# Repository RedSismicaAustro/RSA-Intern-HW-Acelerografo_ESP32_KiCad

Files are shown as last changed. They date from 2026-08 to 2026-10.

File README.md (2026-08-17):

# 🚀 Rediseño y Estandarización de PCB Acelerográfica en KiCad 10 (PCBA JLCPCB)

Este repositorio contiene el espacio de trabajo, documentación de referencia y material de apoyo para el desarrollo de la pasantía de **Joel Suárez** en la **Red Sísmica del Austro (RSA)**.

El objetivo central es capturar, auditar, optimizar y estandarizar el diseño del **Sistema Acelerográfico con ESP32 (SMD)** en el entorno **KiCad 10**, garantizando que el diseño sea 100% compatible con el firmware de adquisición original y esté preparado para ensamblaje automático (**PCBA**) en **JLCPCB**.

---

## 📂 Organización del Repositorio

Para mantener el flujo de trabajo simple y ordenado, el proyecto está estructurado en tres carpetas:

```text
RSA-Intern-HW-Acelerografo_ESP32_KiCad/
│
├── .gitignore                                 # Configurado para ignorar temporales y respaldos de KiCad
├── README.md                                  # Guía operativa e instrucciones de trabajo
│
├── docs/                                      # Documentación técnica de apoyo y planificación
│   ├── Planificacion_Migracion_EAGLE_KiCad.pdf # Plan de trabajo oficial detallado (96 horas)
│   └── especificacion_hardware_original.md    # Detalle de circuitos integrados, valores pasivos y pines
│
├── eagle/                                     # Material de referencia del diseño previo
│   ├── BOM_Assembly.txt                       # Lista de materiales (BOM) con valores, referencias y encapsulados
│   ├── images_schematic/                      # Capturas de los esquemas por bloques (Páginas 1 a 7 y Full)
│   └── images_pcb_3d_view/                    # Vistas 3D de referencia de la placa previa
│
└── kicad/                                     # 👉 Espacio de trabajo exclusivo para el nuevo proyecto KiCad 10
```

---

## 🧭 Metodología de Trabajo y Fases (96 horas)

Dado que el diseño previo proviene de una versión en Autodesk Fusion Electronics / EAGLE sin archivos de proyecto nativos disponibles, el trabajo se desarrollará directamente en **KiCad 10** en la carpeta [`kicad/`](./kicad) siguiendo estas 6 fases:

### 1. Captura de Esquemático y Auditoría de Pines (Pinout Audit - 16 h)
* **Captura en KiCad 10:** Crear el proyecto en [`kicad/`](./kicad) y dibujar los bloques esquemáticos utilizando como referencia las capturas en [`eagle/images_schematic/`](./eagle/images_schematic), la lista de materiales en [`eagle/BOM_Assembly.txt`](./eagle/BOM_Assembly.txt) y la [`especificacion_hardware_original.md`](./docs/especificacion_hardware_original.md).
* **Auditoría estricta contra Firmware:** Cotejar pin a pin la asignación de GPIOs del ESP32 con el código fuente del firmware de adquisición disponible en [RSA Sensor (GitHub)](https://github.com/JorgeZh-hub/RSA_sensor):
  * **ADXL355Z (SPI):** `MOSI`, `MISO`, `SCK`, `CS`.
  * **Tarjeta MicroSD (SPI + Buffer 74LVC125A):** `MOSI`, `MISO`, `SCK`, `CS`.
  * **GPS (UART):** `TX`, `RX`.
  * **RTC DS3231 (I2C + SQW):** `SDA`, `SCL`, interrupción `SQW` (1 Hz).
  * **Conversor USB/Serial (UART):** `TXD0`, `RXD0`, `DTR`, `RTS` hacia el CH340G.

### 2. Estandarización de Componentes y Códigos LCSC (16 h)
* Asignar a cada símbolo el campo de metadatos `LCSC` con el número de parte (*LCSC Part Number*) del catálogo de JLCPCB.
* Priorizar componentes clasificados como **Basic Parts** de JLCPCB para reducir costos de montaje.
* Seleccionar encapsulados SMD estándar adecuados (0805, 0603, 1206, SOT-23, SOIC).

### 3. Gestión de Librerías Locales Relativas (12 h)
* Utilizar la herramienta `jlc2kicadlib` para descargar componentes específicos que no estén en la librería oficial de KiCad.
* Alojar todos los símbolos (`.kicad_sym`), huellas (`.kicad_mod` en carpeta `.pretty`) y modelos 3D (`.step`) dentro de carpetas locales del proyecto (ej. `kicad/libs/`).
* Configurar las rutas mediante variables relativas del entorno KiCad (ej. `${KIPRJMOD}`) para que el repositorio sea **100% portable y autónomo** al clonarse en cualquier computador.

### 4. Layout Físico, Integridad y Optimización (24 h)
* **Desacoplo:** Ubicar condensadores de desacoplo (0.1 µF y 10 µF) lo más próximos posible a los pines `VCC`/`VDD` del ESP32, ADXL355 y RTC.
* **Plano de Masa:** Implementar planos de tierra robustos de cobre (GND) en ambas capas (Top y Bottom).
* **Señales Críticas:** Rutar con trazas cortas y directas las líneas de datos SPI del acelerómetro y MicroSD, minimizando el número de vías.
* **Test Points:** Incluir puntos de prueba accesibles (pads/headers) para señales críticas (`3.3V`, `5V`, `GND`, `TX/RX`, `SQW 1Hz`, bus SPI).
* **Pick & Place:** Colocar al menos 3 marcas fiduciarias (*Fiducials*) en las esquinas de la PCB.
* **DRC:** Ejecutar el Design Rules Check de KiCad y asegurar 0 errores/advertencias.

### 5. Generación y Validación de Archivos de Fabricación (14 h)
* Instalar y utilizar el plugin **Fabrication Toolkit** en KiCad para generar automáticamente el paquete PCBA:
  * Archivos Gerber y NC Drill.
  * Lista de Materiales (`BOM.csv`).
  * Archivo de Posición y Coordenadas (`CPL.csv`).
* Cargar el paquete en el visor web de JLCPCB para auditar y corregir rotaciones u offsets de los componentes SMD.

### 6. Cierre y Documentación (14 h)
* Documentar las decisiones técnicas y optimizaciones realizadas (planos GND, desacoplo, corrección de pines).
* Generar las instrucciones de actualización y exportación en el README final del proyecto.

---

## 🏆 Criterios de Éxito y Entregables Finales

1. **Proyecto KiCad 10 Funcional y Portable:** Esquemático y PCB completos en `kicad/` con librerías locales relativas.
2. **Paquete de Fabricación JLCPCB Validado:** Gerbers, BOM y CPL listos para producción sin requerir correcciones manuales en el visor de JLCPCB.
3. **Auditoría de Pines Verificada:** Informe que certifique la compatibilidad total del pinout con el firmware de adquisición.

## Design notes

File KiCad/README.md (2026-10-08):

# Documentación técnica del PCB acelerográfico ESP32

**Proyecto:** Rediseño y estandarización del sistema acelerográfico de la Red Sísmica del Austro (RSA).  
**Responsable del trabajo según README:** Joel Suárez.  
**Entorno de diseño:** KiCad 10.  
**Fecha de revisión documental:** 7 de octubre de 2026.  
**Estado:** documentación del diseño y paquete exportado; pendiente de certificación eléctrica, de reglas y de ensamblaje.

## 1. Introducción y organización del proyecto

Este documento describe el entorno desarrollado para el PCB acelerográfico ESP32: proyecto KiCad, alimentación, bloques funcionales, bibliotecas locales, selección de componentes y preparación de archivos para fabricación PCBA. La estructura documental toma como referencia el README del Concentrador aportado, adaptando su organización al acelerógrafo. Los componentes, el origen EAGLE/Fusion del diseño y las rutas corresponden al proyecto acelerográfico; no se trasladan los datos del circuito Concentrador.

Las fuentes técnicas son el BOM `Acelerografo_ESP32.csv`, los archivos locales KiCad y las capturas proporcionadas. La organización del repositorio corresponde al árbol de carpetas aportado:

```text
RSA-Intern-HW-Acelerografo_ESP32_KiCad/
├── docs/
├── eagle_Images/
│   ├── images_pcb_3d_view/
│   └── images_schematic/
└── KiCad/
    ├── fabrication/
    ├── libs/
    │   ├── footprint/
    │   ├── JLC2KiCad_lib/
    │   │   └── RSA.pretty/
    │   │       └── packages3d/
    │   ├── LibExt.pretty/
    │   │   └── packages3d/
    │   ├── RSA.pretty/
    │   │   └── packages3d/
    │   └── symbol/
    └── projects/
        └── Acelerografo_ESP32/
            ├── .history/
            ├── production/
            └── _restore_backup_2026-09-14T22-53-35-565/
```

| Directorio | Función en el entorno |
|---|---|
| `docs/` | Documentación técnica del proyecto. |
| `eagle_Images/` | Capturas del esquemático y vistas 3D del diseño de referencia. |
| `KiCad/fabrication/` | Directorio disponible para organizar recursos de fabricación; no se encontraron archivos durante esta revisión. |
| `KiCad/libs/` | Símbolos, huellas y modelos 3D locales. |
| `KiCad/libs/JLC2KiCad_lib/` | Recursos adicionales generados por la herramienta de importación de componentes. |
| `KiCad/projects/Acelerografo_ESP32/` | Proyecto activo: `.kicad_pro`, `.kicad_sch`, `.kicad_pcb`, BOM y tablas de bibliotecas. |
| `KiCad/projects/Acelerografo_ESP32/production/` | Paquete de fabricación exportado mediante Fabrication Toolkit. |
| `.history/` y `_restore_backup_2026-09-14T22-53-35-565/` | Historial y respaldo del proyecto; no constituyen el paquete destinado al fabricante. |

El directorio `KiCad/fabrication/` y la carpeta `production/` del proyecto son ubicaciones diferentes. Los archivos exportados inspeccionados se encuentran en la segunda.
La revisión incluyó las tablas de bibliotecas, las opciones de Fabrication Toolkit, los CSV de producción y el inventario interno del ZIP de Gerbers. No se ejecutaron ERC ni DRC, no se realizó una auditoría completa de las conexiones, no se inspeccionaron gráficamente los Gerbers ni se cargó el paquete en JLCPCB. Tampoco se comprobó el firmware ni la correspondencia comercial de cada LCSC con su encapsulado. Las instrucciones de validación de este documento son pasos pendientes, no resultados aprobados.

## 2. Objetivo del proyecto

Reconstruir, auditar y estandarizar en KiCad 10 el sistema acelerográfico con ESP32 originalmente desarrollado en Autodesk Fusion Electronics/EAGLE, empleando las capturas y documentación disponibles como referencia. La placa integra adquisición de aceleración, almacenamiento local y referencias temporales, y busca mantener la compatibilidad con el firmware original.

El objetivo de fabricación es obtener un proyecto mantenible y portable, con componentes identificados mediante códigos LCSC para el ensamblaje PCBA en JLCPCB y una lista explícita de módulos y conectores instalados manualmente. La compatibilidad con el firmware y la aptitud para fabricación requieren las verificaciones eléctricas y de ensamblaje descritas en este documento.

## 3. Arquitectura general

```text
Entrada 12 V (12V1)
        │
        ▼
Módulo MP2307 (U8, montaje manual)
        │ 5 V
        ▼
LD1117S33 (U4)
        │ 3.3 V / alimentación digital prevista
        ▼
ESP32-WROOM-32 (U1)
        ├── SPI ── ADXL355Z (U3): adquisición acelerográfica
        ├── SPI ── 74LVC125 (U7) / MicroSD1: almacenamiento
        ├── UART ─ GPS1: referencia temporal y posicionamiento
        ├── I²C / SQW ─ RTC (U2) / BT1: reloj y respaldo
        └── UART ─ CH340G (U6) / USB-C (J7): comunicación/programación
```

El diagrama sintetiza la arquitectura prevista en el README y la solicitud de diseño; no reemplaza la auditoría pin a pin. El archivo PCB declara dos capas de cobre, `F.Cu` y `B.Cu`, y un espesor nominal de 1,6 mm. Estos son parámetros del diseño, no una confirmación de fabricación.

### 3.1 Alimentación 12 V → 5 V → 3,3 V

La etapa de reducción de 12 V a 5 V se implementa con un **módulo MP2307**, representado por U8. El CSV conserva el nombre genérico `STEP_DOWN_CONVERTER`; la identificación MP2307 procede de la definición del proyecto aportada por el usuario. La vista 3D muestra una pequeña placa convertidora completa en la zona superior izquierda, con inductor y elementos de regulación propios.

El módulo sustituye la implementación discreta de la etapa conmutada y se instala manualmente. La placa principal conserva condensadores externos: C20 de 220 µF y C21 de 100 nF en la zona de entrada, y C22 de 100 µF, C23 de 100 nF y C24 de 10 nF en la zona del convertidor. Su conexión exacta debe confirmarse en el esquemático; la lista de valores no certifica por sí sola su función eléctrica.

U4, `LD1117S33TR_SOT223`, realiza la regulación prevista de 5 V a 3,3 V. Su footprint es `SOT-223-3_TabPin2` y su código LCSC es C35879. Antes de conectar la electrónica digital, medir la salida del módulo a 5 V y la salida de U4 a 3,3 V; verificar pinout, polaridad, tensión admisible de condensadores, demanda máxima de corriente y disipación térmica. Documentar también el comportamiento con alimentación USB y externa simultánea mediante la revisión de las conexiones reales.

### 3.2 Bloques visibles en la captura

| Bloque | Referencias principales | Descripción y evidencia visual |
|---|---|---|
| Entrada y regulación | 12V1, U8, U4, C20–C24 | Conector de entrada arriba a la derecha, convertidor arriba a la izquierda y regulador U4 en la zona superior. |
| Control y comunicaciones | U1 | Módulo ESP32-WROOM-32 en el borde inferior derecho, con antena hacia el exterior. Revisar keepout en ambas capas. |
| Adquisición | U3 | Huella de la placa ADXL355Z en el lateral derecho, sobre el ESP32; la ausencia de cuerpo 3D no demuestra ausencia de montaje. |
| GPS | GPS1 | Área de breakout GPS en la zona superior derecha, rotulada con PA6H y su contorno mecánico. |
| Almacenamiento | MicroSD1, U7 | Portatarjetas en el lateral izquierdo inferior y buffer próximo a él. |
| Reloj y respaldo | U2, BT1 | RTC en la zona inferior central y huella del soporte de batería en la esquina inferior izquierda. |
| USB/serial | J7, U6 | USB-C en el borde izquierdo y CH340G en la zona central izquierda. |
| Control e indicación | EN1, RTS1, D3, D4 | Dos pulsadores centrales y LEDs distribuidos en la placa. |
| Interconexión y pasivos | J6, J9, J13, J16, J17, J18; R, C, D | Headers, acceso a señales, resistencias, condensadores y diodos según el BOM. |

La captura permite describir placement y presencia de huellas, pero no demuestra continuidad de planos GND, integridad de señales, cumplimiento de reglas ni montaje real. No se asigna aquí una función específica a cada diodo o resistencia sin auditar su red.

### 3.3 PCB final — vista 3D

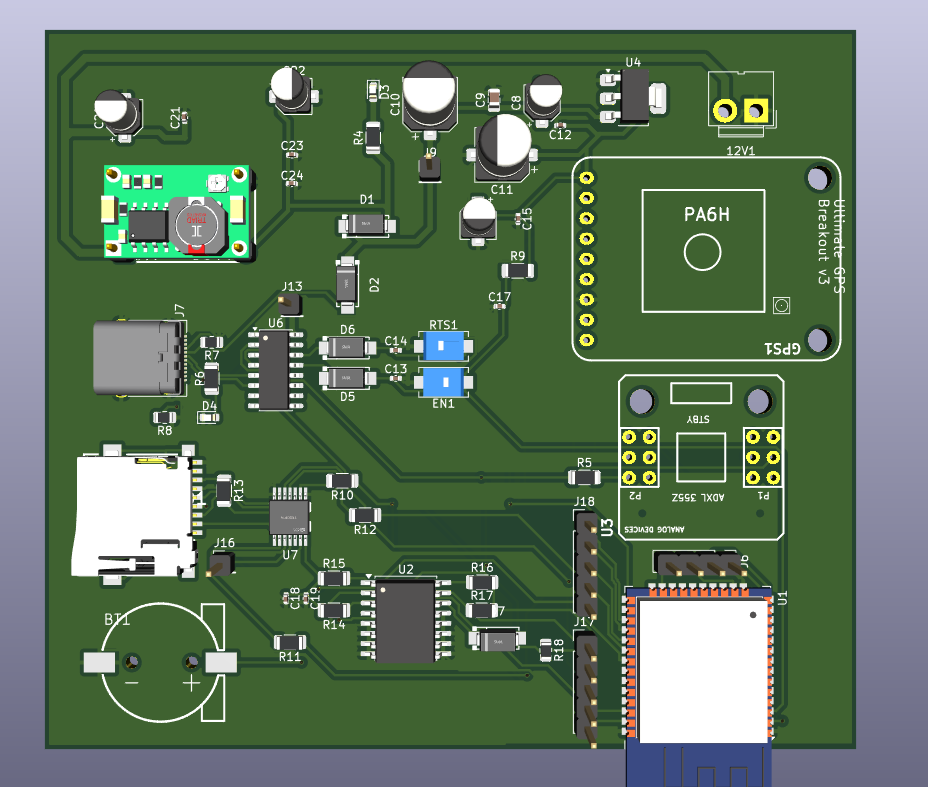
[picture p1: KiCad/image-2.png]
PCB final del acelerógrafo ESP32


**Figura: PCB final presentado por el usuario.** La vista muestra la distribución de la etapa de alimentación, el ESP32, los espacios para GPS y ADXL355, el puerto USB-C, el portatarjetas MicroSD y el RTC con soporte de batería. La imagen documenta la disposición física final mostrada; no representa una fotografía de una placa fabricada ni certifica ERC, DRC o validación en JLCPCB.
## 4. Librerías locales y portabilidad

La captura y `fp-lib-table` muestran dos bibliotecas de huellas específicas del proyecto:

| Apodo en KiCad | Directorio local | Uso identificado en el BOM |
|---|---|---|
| LibsExt | `KiCad/libs/LibExt.pretty` | Soporte CR1220, GPS_BREAKOUT_V3, MicroSD_holder, ADXL355Z y STEP_DOWN_CONVERTER. |
| LibsRSA | `KiCad/libs/RSA.pretty` | Huellas SMA para ES1D y TSSOP-14 para 74LVC125. |

`LibsExt` es el apodo; `LibExt.pretty` es el nombre real del directorio. No deben confundirse. Existen símbolos en `KiCad/libs/symbol/`, un archivo `KiCad/libs/RSA.kicad_sym` y modelos en subdirectorios `packages3d` de las bibliotecas.

**Estado observado:** las tablas aún utilizan rutas absolutas `C:/Users/Suarezc1224/Desktop/...`. Por tanto, la portabilidad no está completada. Además, `sym-lib-table` apunta a directorios para LibsExt y LibsRSA, en lugar de identificar archivos `.kicad_sym`; esta configuración requiere revisión y prueba de resolución de símbolos.

Como el proyecto reside en `KiCad/projects/Acelerografo_ESP32/`, las rutas relativas propuestas son:

```text
LibsExt (huellas): ${KIPRJMOD}/../../libs/LibExt.pretty
LibsRSA (huellas): ${KIPRJMOD}/../../libs/RSA.pretty
LibsRSA (símbolos, si se adopta RSA.kicad_sym): ${KIPRJMOD}/../../libs/RSA.kicad_sym
Modelo 3D local, ejemplo: ${KIPRJMOD}/../../libs/LibExt.pretty/packages3d/Convertidor STEP DOWN.step
```

Para los símbolos externos, registrar cada archivo `.kicad_sym` con el apodo correspondiente, o consolidarlos en una biblioteca válida y actualizar sus identificadores. No apuntar una biblioteca de símbolos KiCad a una carpeta como sustituto de un archivo. Mantener los apodos utilizados por los componentes o reasignarlos de forma coherente.

Después de ajustar las rutas, abrir una copia del repositorio en una ubicación distinta, comprobar símbolos, huellas y vista 3D, y revisar que no queden rutas personales. Los modelos oficiales que usan `${KICAD10_3DMODEL_DIR}` requieren las bibliotecas estándar correspondientes en el equipo receptor. Estas correcciones se documentan como propuestas; no se modificaron los archivos del proyecto durante esta tarea.

## 5. Flujo técnico del entorno desarrollado

El entorno reúne el proyecto KiCad, las bibliotecas locales, el BOM y los archivos de fabricación. Su organización permite mantener la relación entre el circuito, los componentes físicos y el paquete destinado a producción.

1. **Esquemático:** el archivo `Acelerografo_ESP32.kicad_sch` contiene la representación del circuito. Desde el editor se gestionan referencias, valores, conexiones y asignación de huellas.
2. **Bibliotecas:** `KiCad/libs/` reúne símbolos, huellas y modelos 3D. Las tablas del proyecto registran LibsExt y LibsRSA; las rutas relativas propuestas en la sección anterior facilitan trasladar el entorno a otro equipo.
3. **Componentes:** el campo LCSC identifica las piezas previstas para PCBA. Los módulos y conectores de montaje manual se mantienen en la BOM completa, separados del conjunto que se enviará a ensamblaje.
4. **PCB:** `Acelerografo_ESP32.kicad_pcb` contiene la distribución física y el ruteo. La captura 3D permite identificar los bloques y su disposición en la placa.
5. **Exportación:** Fabrication Toolkit genera el paquete en `production/`, con Gerbers, taladros, BOM y posiciones de componentes.
6. **Actualización:** después de cambiar el circuito o el layout, actualizar el PCB desde el esquemático, ejecutar las comprobaciones técnicas y regenerar el paquete para mantener los archivos de fabricación coherentes con el diseño.

Se confirmó la existencia de estos recursos. La revisión documental no incluyó la ejecución de las comprobaciones eléctricas ni la modificación de los archivos KiCad.
### 5.1 Configuración del entorno de trabajo

Abrir `KiCad/projects/Acelerografo_ESP32/Acelerografo_ESP32.kicad_pro` con KiCad 10. Mantener las bibliotecas estándar utilizadas por los footprints del BOM y registrar las bibliotecas locales en las tablas específicas del proyecto. Revisar la resolución de símbolos, huellas y modelos antes de actualizar el circuito.

Para la importación de componentes, disponer de Python y JLC2KiCadLib. Si se utiliza un entorno virtual, puede prepararse desde la raíz del repositorio:

```powershell
python -m venv .venv
.\.venv\Scripts\Activate.ps1
python -m pip install JLC2KiCadLib
jlc2kicadlib --help
```

Estos comandos describen la preparación del entorno y no se ejecutaron en esta revisión. La versión de Python debe ser compatible con la versión instalada de la herramienta; no se presupone que el entorno del Concentrador sea idéntico al del acelerógrafo.

El entorno incluye Fabrication Toolkit para exportar el paquete desde el editor PCB. Si se prepara otro equipo, instalar el complemento desde el administrador de complementos y contenidos de KiCad y comprobar que esté disponible en el editor.

### 5.2 Campos de componentes y mantenimiento

Mantener `Reference`, `Value`, `Footprint` y `LCSC` coherentes entre esquemático, PCB y exportación. `Qty` es la cantidad agrupada en el BOM. Los campos Datasheet, Description, fabricante y número de parte pueden complementar la identificación sin sustituir el LCSC ni el encapsulado real.

Los elementos manuales conservan su huella en la placa. Para excluirlos de los archivos de ensamblaje, revisar sus atributos de BOM y de posición según la configuración mostrada en la sección de fabricación. Mantener una BOM completa independiente para documentar tanto las piezas PCBA como las de instalación posterior.

Las bibliotecas compartidas se deben actualizar de forma controlada; después de cambiar una huella, comprobar pads, numeración, posición y modelo 3D. Mantener las modificaciones locales versionadas junto al proyecto.
## 6. Lista completa de componentes

La tabla se transcribe del CSV aportado sin sustituir valores ni footprints. Hay **32 filas agrupadas, 59 componentes físicos, 22 códigos LCSC únicos**, con **47 componentes previstos para JLCPCB** y **12 para montaje manual**. `—` representa una celda originalmente vacía. MicroSD1 tiene el campo Value vacío en el CSV.

Un código LCSC indica selección de catálogo y destino de ensamblaje previsto; no certifica stock, categoría Basic/Extended, compatibilidad de footprint ni aceptación del pedido.

### 6.1 Componentes con LCSC — ensamblaje JLCPCB previsto

| Reference | Qty | Value | Footprint | LCSC |
|---|---:|---|---|---|
| BT1 | 1 | Battery | LibsExt:CR1220-2-ext | C70381 |
| C8,C16 | 2 | 10uF | Capacitor_SMD:CP_Elec_4x5.4 | C3343 |
| C9 | 1 | 200nF | Capacitor_SMD:C_0805_2012Metric | C344170 |
| C10,C11 | 2 | 100uF | Capacitor_SMD:CP_Elec_6.3x7.7 | C3338 |
| C12,C13,C14,C15,C17,C19,C21,C23 | 8 | 100nF | Capacitor_SMD:C_0402_1005Metric | C1525 |
| C18 | 1 | 1uF | Capacitor_SMD:C_0402_1005Metric | C29266 |
| C20 | 1 | 220uF | Capacitor_SMD:CP_Elec_4x5.4 | C2858857 |
| C22 | 1 | 100uF | Capacitor_SMD:CP_Elec_4x5.4 | C970695 |
| C24 | 1 | 10nF | Capacitor_SMD:C_0402_1005Metric | C15195 |
| D1,D2,D5,D6,D7 | 5 | ES1D | LibsRSA:SMA_L4.4-W2.8-LS5.4-RD | C64878 |
| D3,D4 | 2 | LED | LED_SMD:LED_0603_1608Metric | C2290 |
| EN1,RTS1 | 2 | SW_Push | Button_Switch_SMD:SW_SPST_EVQPE1 | C720477 |
| MicroSD1 | 1 | — | LibsExt:MicroSD_holder | C53223918 |
| R4,R6,R14,R15,R16,R17 | 6 | 4.7k | Resistor_SMD:R_1206_3216Metric | C17936 |
| R5,R9 | 2 | 10k | Resistor_SMD:R_1206_3216Metric | C17902 |
| R7,R8 | 2 | 5.1k | Resistor_SMD:R_0805_2012Metric | C27834 |
| R10,R11,R12,R13 | 4 | 3.3k | Resistor_SMD:R_1206_3216Metric | C26010 |
| R18 | 1 | 200 | Resistor_SMD:R_0805_2012Metric | C17540 |
| U2 | 1 | DS3231M | Package_SO:SOIC-16W_7.5x10.3mm_P1.27mm | C9866 |
| U4 | 1 | LD1117S33TR_SOT223 | Package_TO_SOT_SMD:SOT-223-3_TabPin2 | C35879 |
| U6 | 1 | CH340G | Package_SO:SOIC-16_3.9x9.9mm_P1.27mm | C14267 |
| U7 | 1 | 74LVC125 | LibsRSA:TSSOP-14_L5.0-W4.4-P0.65-LS6.4-BL | C7813 |

### 6.2 Componentes sin LCSC — montaje manual / DNP-PCBA

Los campos LCSC vacíos son intencionales: estos módulos, conectores y elementos externos se excluyen del ensamblaje JLCPCB y se instalan posteriormente. DNP-PCBA significa que no se montan en fábrica, aunque sí forman parte del producto terminado. MicroSD1 y BT1 pertenecen a la tabla anterior porque tienen LCSC; no se excluyen por su categoría física.

| Reference | Qty | Value | Footprint | LCSC |
|---|---:|---|---|---|
| 12V1 | 1 | Conn_01x02 | Connector:JWT_A3963_1x02_P3.96mm_Vertical | — |
| GPS1 | 1 | GPS_BREAKOUT_V3 | LibsExt:GPS_BREAKOUT_V3 | — |
| J6 | 1 | Conn_01x04_Pin | Connector_PinHeader_2.54mm:PinHeader_1x04_P2.54mm_Vertical | — |
| J7 | 1 | USB_C_Receptacle | Connector_USB:USB_C_Receptacle_Amphenol_12401610E4-2A | — |
| J9 | 1 | IN_LD | Connector_PinHeader_2.54mm:PinHeader_1x01_P2.54mm_Vertical | — |
| J13,J16 | 2 | Conn_01x01_Pin | Connector_PinHeader_2.54mm:PinHeader_1x01_P2.54mm_Vertical | — |
| J17,J18 | 2 | Conn_01x05_Pin | Connector_PinHeader_2.54mm:PinHeader_1x05_P2.54mm_Vertical | — |
| U1 | 1 | ESP32-WROOM-32 | RF_Module:ESP32-WROOM-32 | — |
| U3 | 1 | ADXL355Z | LibsExt:ADXL355Z | — |
| U8 | 1 | STEP_DOWN_CONVERTER | LibsExt:STEP_DOWN_CONVERTER | — |

## 7. Importación con jlc2kicadlib

El siguiente comando PowerShell incluye exactamente los 22 códigos únicos del BOM, conservando el orden de primera aparición y los parámetros solicitados. Documenta una operación reproducible; no se ejecutó durante la generación de este informe.

```powershell
jlc2kicadlib `
C70381 C3343 C344170 C3338 C1525 C29266 C2858857 C970695 C15195 C64878 C2290 C720477 C53223918 C17936 C17902 C27834 C26010 C17540 C9866 C35879 C14267 C7813 `
-dir "C:\Users\Suarezc1224\Desktop\RSA-Intern-HW-Acelerografo_ESP32_KiCad\KiCad\libs" `
-symbol_lib RSA `
-symbol_lib_dir . `
-footprint_lib RSA.pretty `
-model_dir packages3d `
--skip_existing
```

Ejecutar en PowerShell con la herramienta instalada y sin espacios después de los acentos graves de continuación. Si cambia la ubicación del repositorio, ajustar `-dir`. Conservar `--skip_existing` y revisar el registro de importación; no asumir que actualiza o corrige componentes ya presentes. La descarga no sustituye la revisión de pinout, pads, orientación y dimensiones. Confirmar las rutas generadas de los modelos 3D y registrar las bibliotecas resultantes bajo los apodos del proyecto.

## 8. Carpeta production y Fabrication Toolkit

La carpeta `KiCad/projects/Acelerografo_ESP32/production/` contiene el paquete generado mediante **Fabrication Toolkit**, según el flujo descrito por el usuario y la presencia de sus opciones de exportación. **Sí se inspeccionó su contenido real a nivel de listado, CSV y entradas del ZIP.** No se realizó una inspección gráfica ni una validación de fabricación.

Los nombres genéricos `BOM.csv` y `CPL.csv` describen los entregables de materiales y posiciones; los archivos existentes usan los nombres siguientes:

| Archivo real | Función |
|---|---|
| `JLPCB_Acele-ESP32.zip` | Paquete de Gerbers y NC Drill. |
| `JLPCB_Acele-ESP32_bom.csv` | Equivalente funcional a BOM.csv: referencias, footprint, cantidad, valor y LCSC. |
| `JLPCB_Acele-ESP32_positions.csv` | Equivalente funcional a CPL.csv: Designator, Mid X, Mid Y, Rotation y Layer. |
| `JLPCB_Acele-ESP32_designators.csv` | Archivo auxiliar de designadores; se confirmó su presencia, sin evaluar su contenido. |
| `netlist.ipc` | Netlist auxiliar; se confirmó su presencia, sin validar conectividad. |

Dentro del ZIP se encontraron:

```text
Acelerografo_ESP32-F_Cu.gtl
Acelerografo_ESP32-B_Cu.gbl
Acelerografo_ESP32-F_Mask.gts
Acelerografo_ESP32-B_Mask.gbs
Acelerografo_ESP32-F_Paste.gtp
Acelerografo_ESP32-B_Paste.gbp
Acelerografo_ESP32-F_Silkscreen.gto
Acelerografo_ESP32-B_Silkscreen.gbo
Acelerografo_ESP32-Edge_Cuts.gm1
Acelerografo_ESP32-PTH.drl
Acelerografo_ESP32-NPTH.drl
Acelerografo_ESP32-PTH-drl_map.gbr
Acelerografo_ESP32-NPTH-drl_map.gbr
```

Los archivos `.drl` corresponden a taladros metalizados (PTH) y no metalizados (NPTH); los mapas asociados apoyan su revisión. No hay archivos literalmente llamados `BOM.csv` o `CPL.csv` en el listado revisado: deben seleccionarse sus equivalentes al cargar el pedido.

### 8.1 Configuración de exclusión y exportación mostrada

En las propiedades del componente, la captura aportada muestra activados **Excluir de la lista de materiales** y **Excluir de los archivos de posición**. **Excluir de la placa** permanece desactivado: el componente conserva su lugar físico en el PCB para el montaje manual.

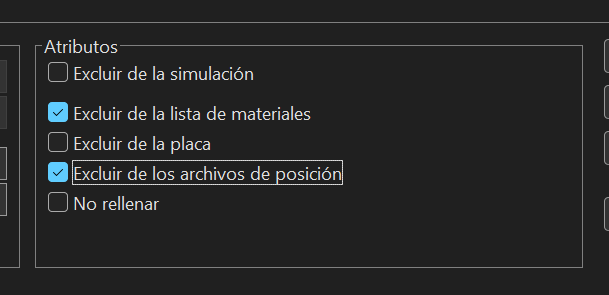
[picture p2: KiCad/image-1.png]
Atributos para excluir elementos manuales de BOM y posiciones


Esta captura ilustra los atributos de un elemento; no demuestra por sí sola que se hayan aplicado a todas las referencias manuales. La exclusión de BOM y posición debe comprobarse para cada elemento de ese grupo. No equivale automáticamente a marcar DNP.

En Fabrication Toolkit se muestra el nombre de exportación **Acelerografo_V1_RevA** y las siguientes opciones:

| Opción | Estado visible |
|---|---|
| Apply automatic component translations | Activada. |
| Apply automatic fill for all zones | Activada. |
| Exclude DNP components from BOM | Activada. |
| Open browser after generation | Activada. |
| Generate backup files | Activada. |
| Plot all active layers | Desactivada. |
| Set User.1 as V-Cut layer | Desactivada. |
| Set User.2 as alternative Edge-Cut layer | Desactivada. |

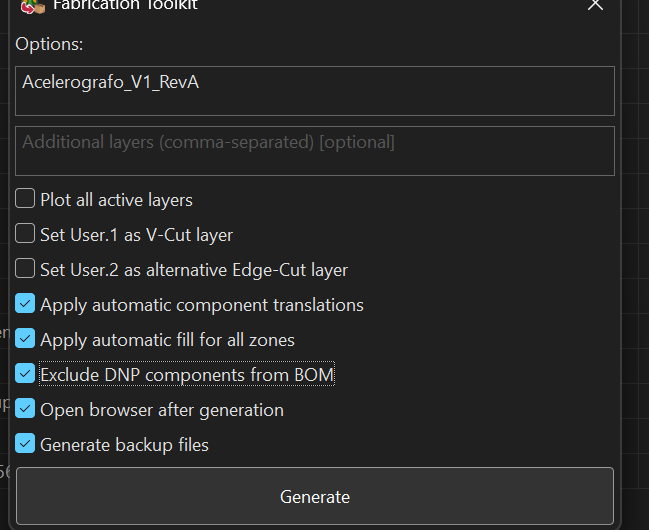
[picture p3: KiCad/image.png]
Configuración de Fabrication Toolkit para Acelerografo_V1_RevA


Después de revisar los atributos y guardar el diseño, ejecutar **Generate**, comprobar el directorio de salida y revisar el contenido del BOM y del CPL. Conservar junto al paquete la revisión del proyecto de la que se exportó.

**Diferencia entre la captura y los archivos inspeccionados:** la nueva captura muestra exclusión DNP activada y el nombre `Acelerografo_V1_RevA`. El archivo de opciones todavía disponible en disco conserva `EXCLUDE DNP: false` y `ARCHIVE_NAME: JLPCB Acele-ESP32`; los archivos encontrados en `production/` usan el prefijo `JLPCB_Acele-ESP32`. Por tanto, la captura documenta la configuración presentada, pero no confirma que el paquete existente se haya regenerado con ella. No se encontró un paquete con el nombre nuevo en el listado revisado.

### 8.2 Observaciones del paquete existente en disco

- El BOM de producción todavía contiene las 32 filas, incluidos los componentes manuales sin LCSC. La opción `EXCLUDE DNP` figura como `false` en `fabrication-toolkit-options.json`. Los campos LCSC vacíos no prueban por sí solos que estos componentes se excluirán del pedido.
- El archivo de posiciones tiene 56 referencias, todas en `top`; incluye componentes de montaje manual. GPS1, U3 y U8 no aparecen en ese archivo. Para el pedido final, comprobar que BOM y CPL contengan exactamente el conjunto autorizado para PCBA.
- MicroSD1 aparece como `MICROSD1` en los archivos de producción y con valor `~`. Normalizar/verificar referencias y completar su descripción en el flujo de pedido sin confundir el marcador con una especificación comercial.
- Debe verificarse cada combinación LCSC/Value/Footprint contra la ficha del fabricante y la selección de JLCPCB. Esta revisión no certifica, por ejemplo, la correspondencia del nombre `DS3231M` con el encapsulado SOIC-16W indicado en el BOM.

Para obtener el paquete definitivo, marcar los componentes manuales como excluidos de PCBA mediante los atributos admitidos por la versión instalada del plugin, activar la exclusión aplicable y regenerar. Alternativamente, preparar BOM y CPL filtrados coherentemente para ensamblaje, conservando por separado la BOM completa. Confirmar el resultado exportado; no basta con cambiar una opción. No se modificó el paquete original durante esta tarea.

## 9. ERC y auditoría eléctrica

1. Abrir el proyecto y resolver las bibliotecas de símbolos antes de revisar el circuito.
2. Ejecutar ERC desde el editor de esquemáticos y registrar fecha, versión, errores y advertencias.
3. Revisar alimentación, pines sin conexión, nombres de red, salidas enfrentadas, entradas flotantes y pines de potencia. Utilizar marcas de no conexión y PWR_FLAG solo cuando el circuito lo justifique.
4. Auditar la cadena 12 V → módulo MP2307 → 5 V → LD1117S33 → 3,3 V, pinout del módulo, masas, polaridad y protección. Comprobar interacción entre USB y fuente externa.
5. Comparar con el firmware GPIO de ADXL355 y MicroSD por SPI, GPS por UART, RTC por I²C/SQW y CH340G por UART/DTR/RTS. Registrar una tabla de señal, GPIO, pin físico y evidencia de firmware.
6. Corregir incidencias y repetir ERC; justificar cualquier exclusión de forma individual. Actualizar el PCB desde el esquemático.

**Resultado de ERC en esta revisión: no ejecutado.** No se declara cero errores ni compatibilidad de firmware verificada.

## 10. DRC y revisión física

1. Seleccionar las reglas de fabricación del servicio y stackup que se contratarán: separación, anchos, vías, taladros y distancias a bordes.
2. Rellenar zonas de cobre y ejecutar DRC en el editor PCB; revisar conexiones sin rutear, cortocircuitos, separaciones, taladros, contorno y courtyards.
3. Revisar continuidad y retornos de GND en ambas capas, desacoplos cercanos a los pines, longitud de SPI y ubicación del acelerómetro respecto de la etapa conmutada.
4. Comprobar keepout de antena ESP32, interferencias mecánicas, acceso a USB/MicroSD, altura de módulos, polaridad y pin 1. Revisar los puntos de prueba y la disposición de fiduciales para el ensamblaje.
5. Resolver errores y advertencias o registrar la justificación técnica de cada excepción.
6. Guardar la revisión aprobada y regenerar todos los archivos de producción desde ella.

**Resultado de DRC en esta revisión: no ejecutado.** La vista 3D y el ZIP existente no acreditan cumplimiento de reglas.

## 11. Validación del pedido en JLCPCB

1. Cargar el ZIP de Gerbers y revisar capas, dimensiones, contorno, máscara, serigrafía y taladros en el visor. Confirmar dos capas y espesor previsto de 1,6 mm según el pedido elegido.
2. Elegir ensamblaje en las caras que correspondan al diseño final; la exportación actual contiene posiciones en top.
3. Cargar el BOM de PCBA y el CPL coherentes, excluyendo las 12 referencias físicas de montaje manual. Mantener su lista para la instalación posterior.
4. Verificar para cada LCSC valor, part number, fabricante, encapsulado, stock y clasificación Basic/Extended. Resolver el Value vacío de MicroSD1 y cualquier incompatibilidad detectada.
5. Revisar la vista de ensamblaje referencia por referencia: coordenadas, unidades, origen, cara, rotación, pin 1 y polaridad. No interpretar automáticamente las coordenadas Y negativas como error; comprobar su resultado en el visor.
6. Comprobar que ninguna pieza manual figure en el ensamblaje solicitado, que no falte ninguna pieza aprobada y que cantidades de BOM y CPL coincidan.
7. Archivar capturas del visor, BOM/CPL aceptados, revisión del proyecto y lista de incidencias resueltas antes de aprobar la fabricación.

**Estado de validación JLCPCB: pendiente; no se cargó ni se aprobó un pedido en esta tarea.**

## 12. Montaje manual y puesta en marcha

Tras recibir la placa ensamblada, inspeccionar soldaduras y orientación de componentes. Instalar 12V1, GPS1, J6, J7, J9, J13, J16, J17, J18, U1, U3 y U8 conforme al esquema y a la lista de montaje manual. Revisar especialmente el sentido de entrada/salida del convertidor y los conectores de módulos.

Antes de energizar, comprobar ausencia de cortocircuitos en las líneas de alimentación. Verificar 5 V y 3,3 V con alimentación controlada antes de conectar los módulos sensibles. Después, comprobar programación y comunicación del ESP32, lectura de los tres ejes del acelerómetro, escritura/lectura de MicroSD, comunicación GPS y funcionamiento del RTC y su respaldo. Registrar mediciones, versión de firmware y resultados.

## 13. Estado técnico de los archivos del entorno

| Elemento | Estado documental observado |
|---|---|
| Proyecto KiCad y vista 3D | Disponibles; revisión eléctrica integral pendiente. |
| BOM completa | 32 filas / 59 componentes, transcrita en este documento. |
| Separación de montaje | 47 componentes PCBA previstos / 12 manuales documentados; exclusión en exportación pendiente. |
| Importación LCSC | Comando preparado con 22 códigos únicos; no ejecutado aquí. |
| Librerías locales | Presentes; rutas absolutas y entradas de símbolos por corregir/verificar. |
| Fabrication Toolkit / production | Paquete presente e inventariado; inspección gráfica y aceptación pendientes. |
| ERC / DRC | Sin resultados certificados en esta revisión. |
| Firmware y pruebas de banco | Pendientes de auditoría y evidencia. |

La liberación para fabricación requiere completar la portabilidad, auditar las partes y conexiones, cerrar ERC/DRC, regenerar BOM/CPL con exclusión coherente del montaje manual y validar el paquete en JLCPCB.

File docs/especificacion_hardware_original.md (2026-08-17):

# 📋 Especificación Técnica Original del Hardware (Versión Previa)

Este documento recopila la especificación técnica de los circuitos, componentes e interfaces de comunicación desarrollados en la etapa previa del diseño acelerográfico SMD. Sirve como referencia directa para la captura y estandarización en KiCad 10.

---

## 1. Arquitectura y Protocolos de Comunicación

El hardware integra el microcontrolador **ESP32** con sensores y periféricos mediante tres buses principales:

| Periférico | Protocolo | Líneas / Señales |
|---|---|---|
| **Acelerómetro ADXL355Z** | SPI | `SCLK`, `MOSI`, `MISO`, `CS` |
| **Tarjeta MicroSD** | SPI (vía buffer 74LVC125A) | `SCLK`, `MOSI`, `MISO`, `CS` |
| **Módulo GPS (FPGMMOPA6H)** | UART | `TX_GPS`, `RX_GPS` |
| **RTC DS3231** | I2C + Interrupción | `SDA`, `SCL`, `SQW` (1 Hz) |
| **Conversor USB-C / Serial** | UART (CH340G) | `TXD0`, `RXD0`, `DTR`, `RTS` |

> 🔗 **Repositorio de Firmware de Referencia:** [RSA Sensor (GitHub)](https://github.com/JorgeZh-hub/RSA_sensor)  
> *Nota Crítica:* Todos los pines del ESP32 asignados en KiCad deben coincidir con la configuración de GPIOs de este firmware.

---

## 2. Sistema de Alimentación

El circuito opera a dos niveles principales de tensión:
1. **Entrada Principal (+12V DC):** Conector XH de 2 pines con protección por diodos.
2. **Etapa Buck (+12V a +5V):** Regulador conmutado basado en el circuito integrado **MP2307** (eficiencia ~85%).
3. **Etapa Lineal (+5V a +3.3V):** Regulador lineal LDO **LD33V** (encapsulado SOT-223) para alimentar el ESP32, sensores y periféricos digitales.
4. **Alimentación USB-C:** Entrada alternativa de +5V por USB con diodos de protección para permitir programación y depuración sin conectar los +12V.

---

## 3. Circuitos Integrados (ICs) Principales

* **ESP32-WROOM-32E:** Microcontrolador SMD con conectividad Wi-Fi y antena externa.
* **ADXL355Z:** Acelerómetro triaxial de bajo ruido y alta resolución (SPI).
* **DS3231:** Reloj en tiempo real de alta precisión con oscilador TCXO integrado (SOIC-16) y batería de respaldo.
* **MP2307:** Regulador Buck Step-Down síncrono (SOIC-8 Exposed Pad).
* **LD33V:** Regulador de voltaje lineal de +3.3V (SOT-223).
* **CH340G:** Puente USB a UART para programación/depuración (SOP-16).
* **74LVC125A:** Buffer cuádruple de nivel lógico con salidas tri-state (TSSOP-14) para aislar las líneas SPI de la tarjeta MicroSD.

---

## 4. Lista de Componentes Pasivos y Semiconductores

### Resistencias
* `R1`, `R3`: 8.2 kΩ (SMD 2512)
* `R2`: 100 kΩ (SMD 2512)
* `R4`: 220 kΩ (Potenciómetro / Trimmer de ajuste)
* `R5`, `R6`, `R7`, `R8`: 3.3 kΩ (SMD 1206) - Pull-ups / Limitadoras
* `R9`, `R10`, `R11`, `R12`, `R16`: 4.7 kΩ (SMD 1206) - Pull-ups I2C y líneas de control
* `R13`: 200 Ω (SMD 1206) - Resistencia limitadora LED
* `R14`, `R15`: 5.11 kΩ (SMD 1206) - Pull-downs de configuración USB-C CC1/CC2
* `R17`: 4.7 kΩ (SMD 2512)
* `R18`, `R19`: 10 kΩ (SMD 1206)

### Capacitores
* `C1`, `C7`, `C9`, `C13`, `C15`, `C16`, `C18`, `C19`: 100 nF (0.1 µF) - Desacoplo de alta frecuencia
* `C2`, `C3`, `C17`: 10 µF - Filtrado y estabilización
* `C4`: 200 nF (0.2 µF)
* `C5`, `C6`: 100 µF - Filtrado de entrada/salida de potencia
* `C8`, `C12`: 12 µF
* `C10`: 4.7 nF
* `C11`: 10 nF
* `C14`: 1 µF

### Inductor y Diodos
* `L1`: 2 µH (SMD 0805) - Inductor de filtro/conmutación
* `D1`, `D3`, `D4`: Diodos rápidos 1N4148 (SMD SOD-123 / SMA)
* `D5`, `D6`: Diodos rectificadores 1N4001 / S1M (SMA/DO-214AC)
* `D2`, `D7`: LEDs indicadores de estado y encendido (SMD 1206)

---

## 5. Puntos de Prueba (Test Points) Implementados

Para la depuración física con osciloscopio o multímetro se requieren puntos de prueba en:
1. **Líneas SPI:** `SCK`, `MOSI`, `MISO`, `CS_ADXL355`, `CS_SD`.
2. **Líneas UART / GPS:** `TX_GPS`, `RX_GPS`, `TXD0`, `RXD0`.
3. **Líneas I2C / Reloj:** `SDA`, `SCL`, señal `SQW` (1 Hz).
4. **Alimentación y Tierra:** `GND`, `+3.3V`, `+5V`, `+12V`.

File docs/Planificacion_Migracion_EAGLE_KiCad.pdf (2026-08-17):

Migración de EAGLE a KiCad

Contexto y Antecedentes

Este proyecto consiste en la continuación, consolidación y optimización del trabajo desarrollado en las etapas previas del sistema de registro continuo de señales acelerométricas:

- Proyecto de Adquisición de Datos (https://github.com/RedSismicaAustro/RSA-Intern-Acelerografo_ESP32) (Firmware y Software): Diseñó el circuito en protoboard y el firmware de adquisición basado en el microcontrolador ESP32, el acelerómetro ADXL355, un RTC, un GPS y almacenamiento en tarjeta SD. Este diseño en protoboard demostró un funcionamiento correcto y estable de la adquisición.
- Proyecto de Diseño de PCB en EAGLE: (https://github.com/RedSismicaAustro/RSA-Intern-HW-Acelerografo_ESP32_SMD) Tomó como referencia el circuito del Proyecto de Adquisición de Datos y diseñó la PCB en EAGLE, estructurándola en una versión modular (con módulos prefabricados) y una versión optimizada en SMD (con componentes de montaje superficial individuales).
- Proyecto de Migración de EDA (https://github.com/RedSismicaAustro/RSA-Intern-SHM) (Altium a KiCad): Estableció el entorno de trabajo estándar de la RSA para la migración de proyectos EDA a KiCad 10, implementando el uso de jlc2kicadlib para la descarga local de componentes y el plugin Fabrication Toolkit para la generación de archivos de ensamblaje automático (PCBA) en JLCPCB.

Objetivo del Proyecto

El objetivo principal de esta pasantía consiste en migrar el diseño de PCB en EAGLE hacia el entorno KiCad 10, aplicando las directrices de estandarización para PCBA en JLCPCB.

Un requerimiento crítico es auditar, corregir y optimizar el diseño migrado para asegurar que sea 100% compatible y trabaje correctamente con el firmware y hardware del Proyecto de Adquisición de Datos original. Esto implica garantizar que la asignación de pines y las líneas de señal/alimentación estén optimizadas para evitar ruidos o pérdidas de datos en la adquisición física final.

Plan de Trabajo Detallado (96 horas)

Fase 1: Importación Nativa y Auditoría de Pines de Hardware/Firmware (16 h)

Objetivo: Migrar los esquemas originales de EAGLE a KiCad y auditar minuciosamente las conexiones para garantizar compatibilidad directa con el firmware del sistema de adquisición.

- Importación nativa: Utilizar la herramienta integrada en KiCad 10 para cargar el esquemático (.sch) y la placa (.brd) de la versión SMD del diseño original.
- Auditoría de asignación de pines (Pinout Audit):
- Comparar de forma exhaustiva las conexiones del ESP32 en el esquemático importado con la asignación de pines (GPIOs) definida en el firmware del Proyecto de Adquisición de Datos.
- Verificar las líneas de comunicación SPI con el ADXL355 (MISO, MOSI, SCK, CS), la interfaz UART con el GPS (TX, RX), el bus I2C y el pin SQW (1 Hz) del RTC, y los pines de control/datos de la tarjeta SD.
- Corregir cualquier discrepancia o pin erróneamente conectado en el esquema para asegurar que la placa final ejecute el firmware original sin necesidad de modificar el código de adquisición de datos.

- Resolución de jerarquías y conectividad: Depurar etiquetas de red, buses y puertos de alimentación para asegurar la integridad eléctrica del diseño.

Fase 2: Estandarización de Componentes SMD y Asignación de Códigos LCSC (16 h)

Objetivo: Adaptar y estandarizar todos los componentes para compatibilidad PCBA de JLCPCB.

- Inventario de componentes: Catalogar los componentes pasivos y activos del circuito para su transición a SMD.
- Estandarización de encapsulados: Seleccionar encapsulados estándar de montaje superficial (ej. 0805, 0603, SOT-23, SOIC) que soporten los niveles de potencia y voltaje requeridos por el circuito en protoboard original.
- Inyección de metadatos LCSC: Añadir de forma masiva el campo personalizado LCSC en todos los símbolos del esquemático.
- Asignación del catálogo: Buscar y asignar los números de parte (LCSC Part Number) en el catálogo de JLCPCB, priorizando el inventario de Basic Parts para optimizar los costos de manufactura.

Fase 3: Gestión de Librerías Locales Relativas (12 h)

Objetivo: Asegurar la portabilidad completa del proyecto mediante el uso de librerías locales y rutas relativas.

- Descarga automatizada: Usar scripts basados en jlc2kicadlib para descargar símbolos (.kicad_sym), huellas (.kicad_mod) y modelos 3D (.step) de los componentes no estándar.
- Estructura local del repositorio: Almacenar los archivos en la carpeta /libs en la raíz del repositorio.
- Rutas relativas: Configurar el proyecto de KiCad utilizando rutas relativas (ej. variables como ${KIPRJMOD}) para que el repositorio sea autónomo al clonarse en cualquier estación de trabajo.
- Auditoría física de huellas: Verificar físicamente la correspondencia geométrica, la posición del Pin 1 y la orientación de los modelos 3D en relación con el footprint.

Fase 4: Optimización del Ruteo, Diseño Físico y Mejoras de Funcionamiento (24 h)

Objetivo: Optimizar el layout físico de la PCB en KiCad para garantizar la correcta adquisición de señales y reducir el ruido en condiciones de trabajo reales.

- Optimización y corrección de la integridad física:
- Planos de alimentación y desacoplo: Añadir o reubicar condensadores de desacoplo de montaje superficial (0.1µF y 10µF) lo más cerca posible de los pines de alimentación (VCC) del ESP32, el acelerómetro ADXL355 y el RTC para filtrar el ruido de la fuente de alimentación.
- Integridad en señales críticas: Rutar de manera directa y con el mínimo uso de vías las líneas de datos de alta velocidad (bus SPI a 250 Hz del ADXL355 y bus de la tarjeta SD) para evitar atenuaciones de señal o pérdidas de tramas.
- Plano de masa robusto: Implementar zonas de cobre dedicadas para la masa (GND) en ambas capas (Top y Bottom) con el fin de minimizar bucles de tierra y blindar el ruido de conmutación electromagnética de la antena del ESP32.

- Puntos de prueba (Test Points): Colocar puntos de prueba accesibles en las líneas críticas (GND, 3.3V, 5V, TX/RX, señal SQW a 1 Hz, y líneas de control de SPI) para facilitar la depuración física con osciloscopio o multímetro.
- Layout y Ensamblaje:
- Colocar al menos 3 marcas fiduciarias (Fiducials) en las esquinas de la placa para calibración visual de las máquinas Pick & Place.
- Ejecutar la Verificación de Reglas de Diseño (DRC) y corregir el 100% de las alertas.

Fase 5: Generación y Validación de Archivos de Fabricación (14 h)

Objetivo: Generar la documentación técnica exacta de producción y validar su visualización final en JLCPCB.

- Generación automatizada: Utilizar el plugin Fabrication Toolkit para exportar:
- Archivos Gerber completos y archivos de perforación NC Drill.
- Lista de Materiales (BOM.csv) formateada con designador, cantidad, footprint, LCSC Part Number y valor.
- Archivo de Coordenadas de Posición (CPL.csv) para colocación de componentes SMD.
- Validación de offsets y rotación: Subir el paquete de archivos al visor web de JLCPCB y validar visualmente la alineación de todos los componentes SMD en la placa.
- Corrección de offsets: Ajustar las rotaciones en el Fabrication Toolkit (ej. desvíos de 90∘ o 180∘ )
hasta que el alineamiento sea idéntico al diseño físico.

Fase 6: Cierre y Documentación Técnica (14 h)

Objetivo: Consolidar la documentación del proyecto migrado para asegurar la reproducibilidad y el mantenimiento.

- Auditoría final comparativa: Documentar formalmente las mejoras de diseño (condensadores de desacoplo, corrección de pines, ruteo optimizado) realizadas con respecto al diseño original de PCB en EAGLE.
- README Operativo del Proyecto: Elaborar el archivo README en la raíz detallando:
- Versión exacta de KiCad utilizada (v10).
- Instrucciones detalladas de instalación y configuración de jlc2kicadlib.
- Resumen de la asignación de pines auditada y validada contra el firmware.
- Guía paso a paso para regenerar los archivos de fabricación mediante el plugin.

Entregables del Pasante (Criterios de Éxito)

Para considerar la migración como aprobada y lista para producción, el pasante deberá proporcionar:

1. Repositorio Autónomo y Portable:
- Archivos de esquemático y PCB completos y funcionales en KiCad 10 con la asignación de pines corregida y auditada.
- Carpeta local | /libs | con símbolos, huellas y modelos 3D con direccionamiento estrictamente
relativo.
2. Paquete de Fabricación Validador (Production Release):
- Archivos Gerber, NC Drill, BOM.csv y CPL.csv listos para ser subidos y procesados por JLCPCB sin correcciones manuales intermedias.
3. Documento Técnico de Auditoría y README:
- README en la raíz que explique el entorno y la estructura.
- Breve informe de auditoría que garantice que la asignación de pines en la PCB coincide exactamente con el firmware de adquisición de datos original, detallando las optimizaciones de ruido y desacoplo aplicadas en la placa.

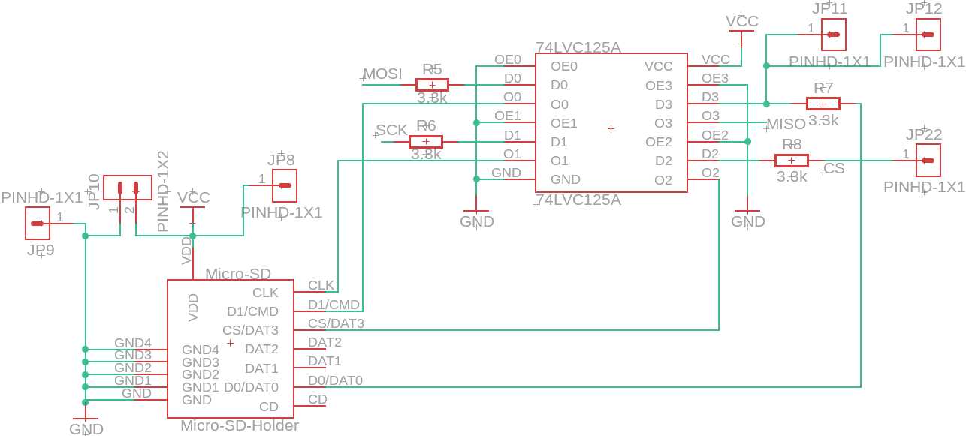
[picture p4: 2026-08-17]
eagle_Images/images_schematic/schematic_6.png

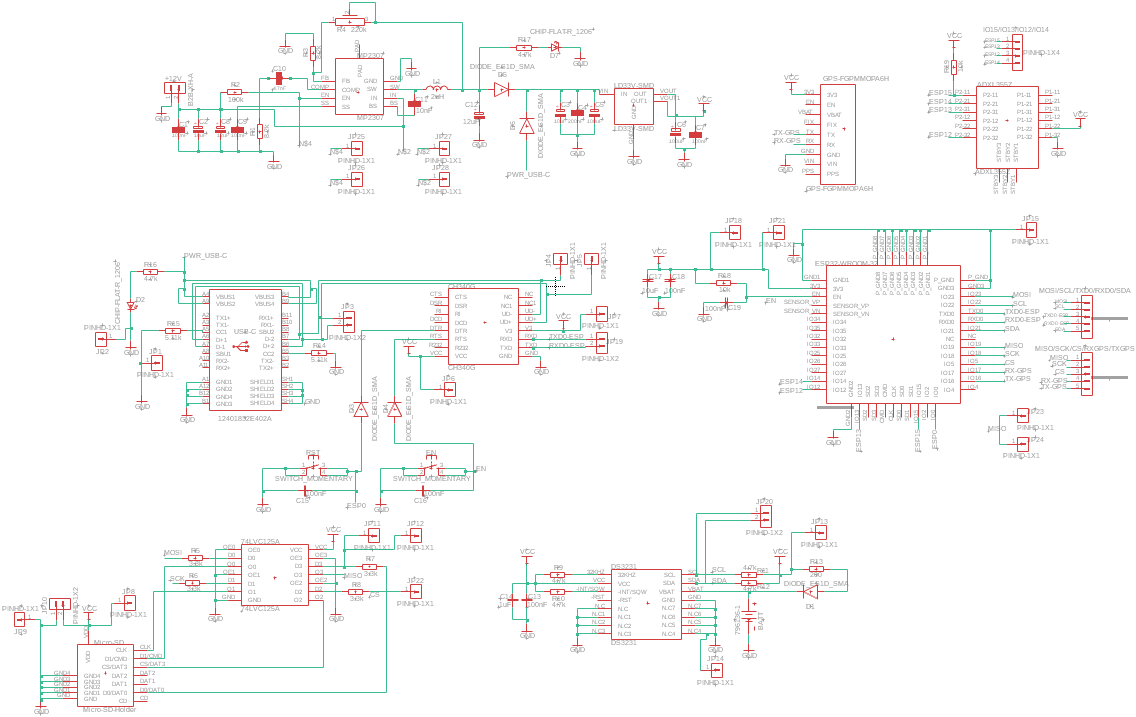
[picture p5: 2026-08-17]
eagle_Images/images_schematic/schematic_Full.png

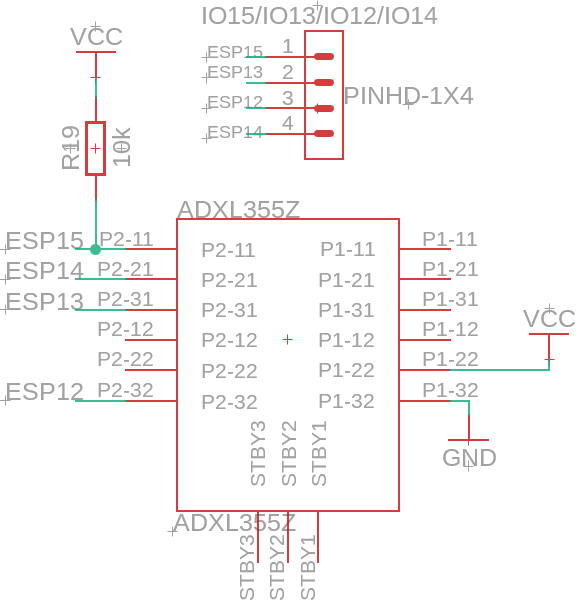
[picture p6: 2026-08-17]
eagle_Images/images_schematic/schematic_3.png

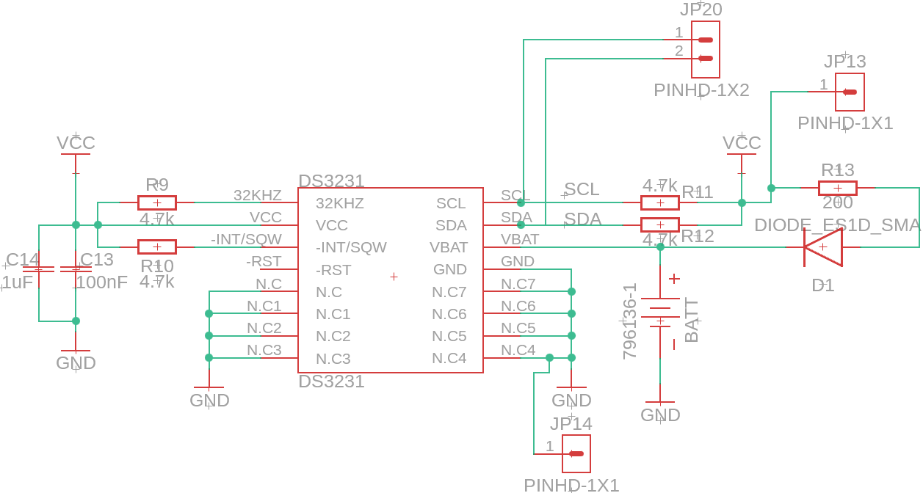
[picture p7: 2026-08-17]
eagle_Images/images_schematic/schematic_7.png

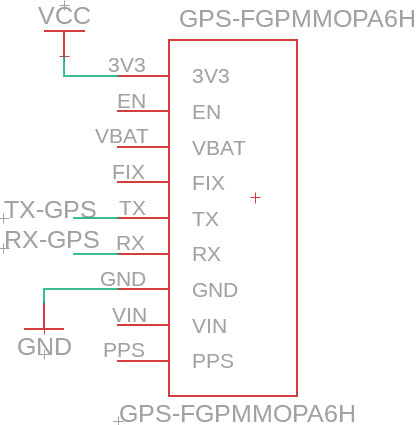
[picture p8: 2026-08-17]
eagle_Images/images_schematic/schematic_2.png

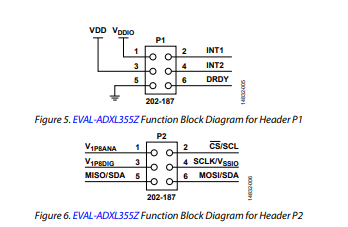
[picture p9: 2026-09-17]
eagle_Images/images_schematic/39320436-b1bcb230-4949-11e8-9dc2-eba227ff7d66.png

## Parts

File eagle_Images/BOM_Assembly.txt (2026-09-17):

"Partlist exported " "from Centro de Fusion: Christian_U Proyecto: PCB_SMD Placa: " "SMD_V1 v116 at 7/6/2025 0:18"                                                                                                                                                                                                                                                                                                                                                                                                                                                                                                                                                                                                                                                                                                                                                                                                                                                                                                                                                                                                                                                                                         
                                                                                                                                                                                                                                                                                                                                                                                                                                                                                                                                                                                                                                                                                                                                                                                                                                                                                                                                                                                                                                                                                                                                                                                                           
"Qty Value         " "   Device                           Package                 " "   Parts                                                                                                                      " "Description                   " "                   " "CATEGORY        " "CELL_DIAMETER " "COLOR " "CONTACTS " "CURRENT_RATING " "DATASHEET                                                                                                 " "DESCRIPTION        " "    " "    " "    " "  " "     " "    " "    " "   " "           " "  " "     " "      " "           " "          " "   " "         " "        " "       " "      " "       " "        " "     " "FORWARD_CURRENT " "FORWARD_VOLTAGE " "GENDER     " "MANUFACTURER " "            " "          " "MATERIAL_CORE " "MPN           " "OPERATING_TEMP " "OPERATING_TEMPERATURE " "PACKAGE_SIZE " "PACKAGE_TYPE  " "PART_STATUS " "PITCH            "  "RATING " "REVERSE_VOLTAGE " "ROHS      " "ROHS_COMPLIANT " "SERIES " "SUB-CATEGORY " "SUBCATEGORY             " "TEMPERATURE_COEFFICIENT " "THERMALLOSS " "TOLERANCE " "TYPE    " "            " "              " "     " "VOLTAGE_RATING " "ZENER_VOLTAGE" 
"1   100k          " "   RESISTOR__CHIP-2512(6332-METRIC) RESC6332X71             " "   R2                                                                                                                         " "Resistor Fixed - Generic      " "                   " "Resistor        " "              " "      " "         " "               " "                                                                                                          " "                   " "    " "    " "    " "  " "     " "    " "    " "   " "           " "  " "     " "      " "           " "          " "   " "         " "        " "       " "      " "       " "        " "     " "                " "                " "           " "             " "            " "          " "              " "              " "               " "                      " "             " "              " "            " "                 "  "       " "                " "          " "               " "       " "Fixed        " "                        " "                        " "            " "          " "        " "            " "              " "     " "               " "             " 
"3   100nF         " "   CAPACITORCERAMIC-2.54MM          CAP-THRU-2.54MM         " "   C1, C7, C9                                                                                                                 " "Capacitor - Generic           " "                   " "                " "              " "      " "         " "               " "                                                                                                          " "                   " "    " "    " "    " "  " "     " "    " "    " "   " "           " "  " "     " "      " "           " "          " "   " "         " "        " "       " "      " "       " "        " "     " "                " "                " "           " "             " "            " "          " "              " "              " "               " "                      " "             " "              " "            " "                 "  "       " "                " "          " "               " "       " "             " "                        " "                        " "            " "          " "        " "            " "              " "     " "               " "             " 
"5   100nF         " "   C_CHIP-0603(1608-METRIC)         CAPC1608X85             " "   C13, C15, C16, C18, C19                                                                                                    " "Capacitor - Generic           " "                   " "Capacitor       " "              " "      " "         " "               " "                                                                                                          " "                   " "    " "    " "    " "  " "     " "    " "    " "   " "           " "  " "     " "      " "           " "          " "   " "         " "        " "       " "      " "       " "        " "     " "                " "                " "           " "             " "            " "          " "              " "              " "               " "                      " 603             "Surface Mount " "            " "                 "  "       " "                " "          " "               " "       " "             " "Ceramic Capacitors      " "                        " "            " "          " "MLCC    " "            " "              " "     " "               " "             " 
"2   100uF         " "   CAPACITOR-POLRADIAL-5MM-DIA      CAPPRD254W65D500H1150B  " "   C5, C6                                                                                                                     " "Capacitor Polarised - Generic " "                   " "                " "              " "      " "         " "               " "                                                                                                          " "                   " "    " "    " "    " "  " "     " "    " "    " "   " "           " "  " "     " "      " "           " "          " "   " "         " "        " "       " "      " "       " "        " "     " "                " "                " "           " "             " "            " "          " "              " "              " "               " "                      " "             " "              " "            " "                 "  "       " "                " "          " "               " "       " "             " "                        " "                        " "            " "          " "        " "            " "              " "     " "               " "             " 
"2   10k           " "   RESISTOR__CHIP-1206(3216-METRIC) RESC3216X70             " "   R18, R19                                                                                                                   " "Resistor Fixed - Generic      " "                   " "Resistor        " "              " "      " "         " "               " "                                                                                                          " "                   " "    " "    " "    " "  " "     " "    " "    " "   " "           " "  " "     " "      " "           " "          " "   " "         " "        " "       " "      " "       " "        " "     " "                " "                " "           " "             " "            " "          " "              " "              " "               " "                      " "             " "              " "            " "                 "  "       " "                " "          " "               " "       " "Fixed        " "                        " "                        " "            " "          " "        " "            " "              " "     " "               " "             " 
"1   10nF          " "   CAPACITORCERAMIC-2.54MM          CAP-THRU-2.54MM         " "   C11                                                                                                                        " "Capacitor - Generic           " "                   " "                " "              " "      " "         " "               " "                                                                                                          " "                   " "    " "    " "    " "  " "     " "    " "    " "   " "           " "  " "     " "      " "           " "          " "   " "         " "        " "       " "      " "       " "        " "     " "                " "                " "           " "             " "            " "          " "              " "              " "               " "                      " "             " "              " "            " "                 "  "       " "                " "          " "               " "       " "             " "                        " "                        " "            " "          " "        " "            " "              " "     " "               " "             " 
"2   10uF          " "   CAPACITOR-POLRADIAL-5MM-DIA      CAPPRD254W65D500H1150B  " "   C2, C3                                                                                                                     " "Capacitor Polarised - Generic " "                   " "                " "              " "      " "         " "               " "                                                                                                          " "                   " "    " "    " "    " "  " "     " "    " "    " "   " "           " "  " "     " "      " "           " "          " "   " "         " "        " "       " "      " "       " "        " "     " "                " "                " "           " "             " "            " "          " "              " "              " "               " "                      " "             " "              " "            " "                 "  "       " "                " "          " "               " "       " "             " "                        " "                        " "            " "          " "        " "            " "              " "     " "               " "             " 
"1   10uF          " "   C_CHIP-1206(3216-METRIC)         CAPC3216X135            " "   C17                                                                                                                        " "Capacitor - Generic           " "                   " "Capacitor       " "              " "      " "         " "               " "                                                                                                          " "                   " "    " "    " "    " "  " "     " "    " "    " "   " "           " "  " "     " "      " "           " "          " "   " "         " "        " "       " "      " "       " "        " "     " "                " "                " "           " "             " "            " "          " "              " "              " "               " "                      " 1206            "Surface Mount " "            " "                 "  "       " "                " "          " "               " "       " "             " "Ceramic Capacitors      " "                        " "            " "          " "MLCC    " "            " "              " "     " "               " "             " 
"1   12401832E402A " "   12401832E402A                    12401832E402A           " "   USB-C                                                                                                                      " "USB(3.1) Type-C- RCPT- 24POS- " "SMD-THT-R/A        " "USB Connector   " "              " "      " 24          "5A             " "https://cdn.amphenol-cs.com/media/wysiwyg/files/documentation/datasheet/inputoutput/io_usb_3_2_type_c.pdf " "USB-C (USB TYPE-C) " "USB " "3.2 " "Gen " 2    "(USB " "3.1 " "Gen " "2- " "Superspeed " "+ " "(USB " "3.1)) " "Receptacle " "Connector " 24    "Position " "Surface " "Mount- " "Right " "Angle- " "Through " "Hole " "                " "                " "Receptacle " "Amphenol ICC " "(Commercial " "Products) " "              " "12401832E402A " "               " "-40? ~ 85?            " "NA           " "SMD           " "ACTIVE      " "                 "  "       " "                " "COMPLIANT " "               " "NA     " "             " "USB TYPE-C              " "                        " "            " "          " "Surface " "Mount-Right " "Angle-Through " "Hole " "NA             " "             " 
"2   12uF          " "   CAPACITOR-POLRADIAL-5MM-DIA      CAPPRD254W65D500H1150B  " "   C8, C12                                                                                                                    " "Capacitor Polarised - Generic " "                   " "                " "              " "      " "         " "               " "                                                                                                          " "                   " "    " "    " "    " "  " "     " "    " "    " "   " "           " "  " "     " "      " "           " "          " "   " "         " "        " "       " "      " "       " "        " "     " "                " "                " "           " "             " "            " "          " "              " "              " "               " "                      " "             " "              " "            " "                 "  "       " "                " "          " "               " "       " "             " "                        " "                        " "            " "          " "        " "            " "              " "     " "               " "             " 
"1   1uF           " "   C_CHIP-0603(1608-METRIC)         CAPC1608X85             " "   C14                                                                                                                        " "Capacitor - Generic           " "                   " "Capacitor       " "              " "      " "         " "               " "                                                                                                          " "                   " "    " "    " "    " "  " "     " "    " "    " "   " "           " "  " "     " "      " "           " "          " "   " "         " "        " "       " "      " "       " "        " "     " "                " "                " "           " "             " "            " "          " "              " "              " "               " "                      " 603             "Surface Mount " "            " "                 "  "       " "                " "          " "               " "       " "             " "Ceramic Capacitors      " "                        " "            " "          " "MLCC    " "            " "              " "     " "               " "             " 
"1   200           " "   RESISTOR__CHIP-1206(3216-METRIC) RESC3216X70             " "   R13                                                                                                                        " "Resistor Fixed - Generic      " "                   " "Resistor        " "              " "      " "         " "               " "                                                                                                          " "                   " "    " "    " "    " "  " "     " "    " "    " "   " "           " "  " "     " "      " "           " "          " "   " "         " "        " "       " "      " "       " "        " "     " "                " "                " "           " "             " "            " "          " "              " "              " "               " "                      " "             " "              " "            " "                 "  "       " "                " "          " "               " "       " "Fixed        " "                        " "                        " "            " "          " "        " "            " "              " "     " "               " "             " 
"1   200nF         " "   CAPACITORCERAMIC-2.54MM          CAP-THRU-2.54MM         " "   C4                                                                                                                         " "Capacitor - Generic           " "                   " "                " "              " "      " "         " "               " "                                                                                                          " "                   " "    " "    " "    " "  " "     " "    " "    " "   " "           " "  " "     " "      " "           " "          " "   " "         " "        " "       " "      " "       " "        " "     " "                " "                " "           " "             " "            " "          " "              " "              " "               " "                      " "             " "              " "            " "                 "  "       " "                " "          " "               " "       " "             " "                        " "                        " "            " "          " "        " "            " "              " "     " "               " "             " 
"1   220k          " "   PV36P                            PV36P                   " "   R4                                                                                                                         " "Rectangular Trimmer Potentiome" "ters - PV36 Series " "Potentiometers  " "              " "      " "         " "               " "https://www.bourns.com/docs/Product-Datasheets/pv36.pdf                                                   " "0.5W 1/2W PC Pins T" "hrou" "gh H" "ole " "Tr" "immer" " Pot" "enti" "ome" "ter Cermet " 25   ".0 Tu" "rn Sid" "e Adjustmen" "t         " "   " "         " "        " "       " "      " "       " "        " "     " "                " "                " "           " "Bourns Inc.  " "            " "          " "              " "PV36Px        " "               " "-55﯃ ~ 125﯃         NA" "           TH" "T           AC" "TIVE        " "                 "  "       " "              CO" "MPLIANT   " "             PV" 36        "           Tr" "immer Potentiometers  ﯱ0" "0ppm/﯃              0.5 " "W       ﯱ0% " "     Side " "Adjustme" "nt Triangle " "Leads         " "     " "               " "        "      
"1   2uH           " "   L_CHIP-0805(2012-METRIC)         INDC2009X120            " "   L1                                                                                                                         " "Inductor Fixed - Generic      " "                   " "Inductors       " "              " "      " "         " "               " "                                                                                                          " "Chip  2.00 X 0.90 X" " 1.2" "0 mm" " bod" "y " "0805(" 2012   "-MET" "RIC" ")          " "  " "     " "      " "           " "          " "   " "         " "        " "       " "      " "       " "        " "     " "                " "                " "           " "             " "            " "          " "              " "              " "               " "                      " 805             "Surface Mount " "            " "                 "  "       " "                " "          " "               " "       " "             " "                        " "                        " "            " "          " "        " "            " "              " "     " "               " "             " 
"4   3.3k          " "   RESISTOR__CHIP-1206(3216-METRIC) RESC3216X70             " "   R5, R6, R7, R8                                                                                                             " "Resistor Fixed - Generic      " "                   " "Resistor        " "              " "      " "         " "               " "                                                                                                          " "                   " "    " "    " "    " "  " "     " "    " "    " "   " "           " "  " "     " "      " "           " "          " "   " "         " "        " "       " "      " "       " "        " "     " "                " "                " "           " "             " "            " "          " "              " "              " "               " "                      " "             " "              " "            " "                 "  "       " "                " "          " "               " "       " "Fixed        " "                        " "                        " "            " "          " "        " "            " "              " "     " "               " "             " 
"5   4.7k          " "   RESISTOR__CHIP-1206(3216-METRIC) RESC3216X70             " "   R9, R10, R11, R12, R16                                                                                                     " "Resistor Fixed - Generic      " "                   " "Resistor        " "              " "      " "         " "               " "                                                                                                          " "                   " "    " "    " "    " "  " "     " "    " "    " "   " "           " "  " "     " "      " "           " "          " "   " "         " "        " "       " "      " "       " "        " "     " "                " "                " "           " "             " "            " "          " "              " "              " "               " "                      " "             " "              " "            " "                 "  "       " "                " "          " "               " "       " "Fixed        " "                        " "                        " "            " "          " "        " "            " "              " "     " "               " "             " 
"1   4.7k          " "   RESISTOR__CHIP-2512(6332-METRIC) RESC6332X71             " "   R17                                                                                                                        " "Resistor Fixed - Generic      " "                   " "Resistor        " "              " "      " "         " "               " "                                                                                                          " "                   " "    " "    " "    " "  " "     " "    " "    " "   " "           " "  " "     " "      " "           " "          " "   " "         " "        " "       " "      " "       " "        " "     " "                " "                " "           " "             " "            " "          " "              " "              " "               " "                      " "             " "              " "            " "                 "  "       " "                " "          " "               " "       " "Fixed        " "                        " "                        " "            " "          " "        " "            " "              " "     " "               " "             " 
"1   4.7nF         " "   CAPACITORCERAMIC-2.54MM          CAP-THRU-2.54MM         " "   C10                                                                                                                        " "Capacitor - Generic           " "                   " "                " "              " "      " "         " "               " "                                                                                                          " "                   " "    " "    " "    " "  " "     " "    " "    " "   " "           " "  " "     " "      " "           " "          " "   " "         " "        " "       " "      " "       " "        " "     " "                " "                " "           " "             " "            " "          " "              " "              " "               " "                      " "             " "              " "            " "                 "  "       " "                " "          " "               " "       " "             " "                        " "                        " "            " "          " "        " "            " "              " "     " "               " "             " 
"2   5.11k         " "   RESISTOR__CHIP-1206(3216-METRIC) RESC3216X70             " "   R14, R15                                                                                                                   " "Resistor Fixed - Generic      " "                   " "Resistor        " "              " "      " "         " "               " "                                                                                                          " "                   " "    " "    " "    " "  " "     " "    " "    " "   " "           " "  " "     " "      " "           " "          " "   " "         " "        " "       " "      " "       " "        " "     " "                " "                " "           " "             " "            " "          " "              " "              " "               " "                      " "             " "              " "            " "                 "  "       " "                " "          " "               " "       " "Fixed        " "                        " "                        " "            " "          " "        " "            " "              " "     " "               " "             " 
"1   74LVC125A     " "   74LVC125A                        74LVC125A               " "   74LVC125A                                                                                                                  " "                              " "                   " "                " "              " "      " "         " "               " "                                                                                                          " "                   " "    " "    " "    " "  " "     " "    " "    " "   " "           " "  " "     " "      " "           " "          " "   " "         " "        " "       " "      " "       " "        " "     " "                " "                " "           " "             " "            " "          " "              " "              " "               " "                      " "             " "              " "            " "                 "  "       " "                " "          " "               " "       " "             " "                        " "                        " "            " "          " "        " "            " "              " "     " "               " "             " 
"1   796136-1      " "   796136-1                         796136-1                " "   BATT                                                                                                                       " "Battery Holder - Coin Cell SMD" " 20.0mm            " "Battery Holders " "20.0mm        " "      " "         " "               " "https://www.te.com/en/product-796136-1.datasheet.pdf                                                      " "Battery Holder (Ope" "n) C" "oin " "20.0" "mm" " 1 Ce" "ll S" "MD (" "SMT" ") Tab      " "  " "     " "      " "           " "          " "   " "         " "        " "       " "      " "       " "        " "     " "                " "                " "           " "TE Connectivi" "ty AMP Conne" "ctors     " "              " "796136-1      " "               " "-40﯃ ~ 85﯃          20" "32         Su" "rface Mount Ac" "tive        " "                 "  "       " "              Co" "mpliant   " "             AM" "P      " "           Co" "in Cell Holder          " "                        " "            " "        Re" "tainer  " "            " "              " "     " "               " "           "
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

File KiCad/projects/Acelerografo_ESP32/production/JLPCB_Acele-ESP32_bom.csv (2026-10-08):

Designator | Footprint | Quantity | Value | LCSC Part #
12V1 | JWT_A3963_1x02_P3.96mm_Vertical | 1 | Conn_01x02
BT1 | CR1220-2-ext | 1 | Battery | C70381
C10, C11 | CP_Elec_6.3x7.7 | 2 | 100uF | C3338
C12, C13, C14, C15, C17, C19, C21, C23 | 0402 | 8 | 100nF | C1525
C16, C8 | CP_Elec_4x5.4 | 2 | 10uF | C3343
C18 | 0402 | 1 | 1uF | C29266
C20 | CP_Elec_4x5.4 | 1 | 220uF | C2858857
C22 | CP_Elec_4x5.4 | 1 | 100uF | C970695
C24 | 0402 | 1 | 10nF | C15195
C9 | 0805 | 1 | 200nF | C344170
D1, D2, D5, D6, D7 | SMA_L4.4-W2.8-LS5.4-RD | 5 | ES1D | C64878
D3, D4 | 0603 | 2 | LED | C2290
EN1, RTS1 | SW_SPST_EVQPE1 | 2 | SW_Push | C720477
GPS1 | GPS_BREAKOUT_V3 | 1 | GPS_BREAKOUT_V3
J13, J16 | PinHeader_1x01_P2.54mm_Vertical | 2 | Conn_01x01_Pin
J17, J18 | PinHeader_1x05_P2.54mm_Vertical | 2 | Conn_01x05_Pin
J6 | PinHeader_1x04_P2.54mm_Vertical | 1 | Conn_01x04_Pin
J7 | USB_C_Receptacle_Amphenol_12401610E4-2A | 1 | USB_C_Receptacle
J9 | PinHeader_1x01_P2.54mm_Vertical | 1 | IN_LD
MICROSD1 | MicroSD_holder | 1 | ~ | C53223918
R10, R11, R12, R13 | 1206 | 4 | 3.3k | C26010
R14, R15, R16, R17, R4, R6 | 1206 | 6 | 4.7k | C17936
R18 | 0805 | 1 | 200 | C17540
R5, R9 | 1206 | 2 | 10k | C17902
R7, R8 | 0805 | 2 | 5.1k | C27834
U1 | ESP32-WROOM-32 | 1 | ESP32-WROOM-32
U2 | SOIC-16W_7.5x10.3mm_P1.27mm | 1 | DS3231M | C9866
U3 | ADXL355Z | 1 | ADXL355Z
U4 | SOT-223-3_TabPin2 | 1 | LD1117S33TR_SOT223 | C35879
U6 | SOIC-16_3.9x9.9mm_P1.27mm | 1 | CH340G | C14267
U7 | TSSOP-14_L5.0-W4.4-P0.65-LS6.4-BL | 1 | 74LVC125 | C7813
U8 | STEP_DOWN_CONVERTER | 1 | STEP_DOWN_CONVERTER

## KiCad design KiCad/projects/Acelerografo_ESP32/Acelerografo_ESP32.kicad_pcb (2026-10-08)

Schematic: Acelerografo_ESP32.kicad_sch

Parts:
12V1: Conn_01x02; JWT_A3963_1x02_P3.96mm_Vertical
BT1: Battery; CR1220-2-ext; LCSC C70381
C8, C16: 10uF; CP_Elec_4x5.4; LCSC C3343
C9: 200nF; C_0805_2012Metric; LCSC C344170
C10, C11: 100uF; CP_Elec_6.3x7.7; LCSC C3338
C12, C13, C14, C15, C17, C19, C21, C23: 100nF; C_0402_1005Metric; LCSC C1525
C18: 1uF; C_0402_1005Metric; LCSC C29266
C20: 220uF; CP_Elec_4x5.4; LCSC C2858857
C22: 100uF; CP_Elec_4x5.4; LCSC C970695
C24: 10nF; C_0402_1005Metric; LCSC C15195
D1, D2, D5, D6, D7: ES1D; SMA_L4.4-W2.8-LS5.4-RD; LCSC C64878
D3, D4: LED; LED_0603_1608Metric; LCSC C2290
EN1: SW_Push; SW_SPST_EVQPE1; LCSC C720477
GPS1: GPS_BREAKOUT_V3
J6: Conn_01x04_Pin; PinHeader_1x04_P2.54mm_Vertical
J7: USB_C_Receptacle; USB_C_Receptacle_Amphenol_12401610E4-2A
J9: IN_LD; PinHeader_1x01_P2.54mm_Vertical
J13, J16: Conn_01x01_Pin; PinHeader_1x01_P2.54mm_Vertical
J17, J18: Conn_01x05_Pin; PinHeader_1x05_P2.54mm_Vertical
MicroSD1: MicroSD_holder; LCSC C53223918
R4, R6, R14, R15, R16, R17: 4.7k; R_1206_3216Metric; LCSC C17936
R5, R9: 10k; R_1206_3216Metric; LCSC C17902
R7, R8: 5.1k; R_0805_2012Metric; LCSC C27834
R10, R11, R12, R13: 3.3k; R_1206_3216Metric; LCSC C26010
R18: 200; R_0805_2012Metric; LCSC C17540
RTS1: SW_Push; SW_SPST_EVQPE1; LCSC C720477
U1: ESP32-WROOM-32
U2: DS3231M; SOIC-16W_7.5x10.3mm_P1.27mm; LCSC C9866
U3: ADXL355Z
U4: LD1117S33TR_SOT223; SOT-223-3_TabPin2; LCSC C35879
U6: CH340G; SOIC-16_3.9x9.9mm_P1.27mm; LCSC C14267
U7: 74LVC125; TSSOP-14_L5.0-W4.4-P0.65-LS6.4-BL; LCSC C7813
U8: STEP_DOWN_CONVERTER

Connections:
/BATT: BT1.1 (+), D7.1 (K), U2.14 (VBAT)
/CS: J18.3, R11.1, U1.29 (IO5)
/D3-SD: MicroSD1.7 (DAT0), R13.1
/D+: J7.A6 (D+), J7.B6 (D+), U6.5 (UD+)
/D-: J7.A7 (D-), J7.B7 (D-), U6.6 (UD-)
/EN: C13.1, C17.2, D5.2 (A), EN1.1, R9.1, U1.3 (EN)
/ESP0: C14.1, D6.2 (A), RTS1.2, U1.25 (IO0)
/ESP12: J6.2, U1.14 (IO12), U3.12 (MISO/SDA)
/ESP13: J6.3, U1.16 (IO13), U3.9 (MOSI/SDA)
/ESP14: J6.1, U1.13 (IO14), U3.8 (SCLK/GND)
/ESP15: J6.4, R5.2, U1.23 (IO15), U3.7 (CS/SCL)
/MISO: J16.1 (Pin_1_1), J18.5, U1.31 (IO19), U7.11
/MOSI: J17.5, R10.1, U1.37 (IO23)
/Out0-SD: MicroSD1.3 (CMD), U7.3
/Out1-SD: MicroSD1.5 (CLK), U7.6
/Out2-SD: MicroSD1.2 (CD/DAT3), U7.8
/PWR_USB-C: D2.2 (A), J7.A4 (VBUS), J7.A9 (VBUS), J7.B4 (VBUS), J7.B9 (VBUS), R6.2
/RX-GPS: GPS1.3 (RXD), J18.2, U1.28 (IO17)
/RXD0-ESP: J17.2, U6.3 (RXD)
/SCK: J18.4, R12.1, U1.30 (IO18)
/SCL: J17.4, R16.1, U1.36 (IO22), U2.16 (SCL)
/SDA: J17.1, R17.1, U2.15 (SDA)
/TX-GPS: GPS1.4 (TXD), J18.1, U1.27 (IO16)
/TXD0-ESP: J17.3, U6.2 (TXD)
GND: 12V1.1, BT1.2 (-), C8.2, C9.2, C10.2, C11.2, C12.2, C13.2, C14.2, C15.2, C16.2, C17.1, C18.2, C19.2, C20.2, C21.2, C22.2, C23.2, C24.2, D3.1 (K), D4.1 (K), EN1.2, GPS1.2 (GND), J7.A1 (GND), J7.A12 (GND), J7.B1 (GND), J7.B12 (GND), J7.SH (SHIELD), MicroSD1.6 (GND), MicroSD1.9 (SH), R7.1, R8.1, RTS1.1, U1.1 (GND), U1.15 (GND), U1.38 (GND), U1.39 (GND), U2.5 (GND), U2.6 (GND), U2.7 (GND), U2.8 (GND), U2.9 (GND), U2.10 (GND), U2.11 (GND), U2.12 (GND), U2.13 (GND), U3.6 (GND), U4.1 (GND), U6.1 (GND), U7.1, U7.4, U7.7 (GND), U7.10, U7.13, U8.2 (IN-), U8.4 (OUT-)
unnamed: 12V1.2, C20.1, C21.1, U8.1 (IN+)
unnamed: C22.1, C23.1, C24.1, D1.2 (A), R4.1, U8.3 (OUT+)
unnamed: C8.1, C9.1, C10.1, D1.1 (K), D2.1 (K), J9.1 (Pin_1_1), U4.3 (VI)
unnamed: D3.2 (A), R4.2
unnamed: D4.2 (A), R6.1
unnamed: D5.1 (K), U6.13 (~DTR)
unnamed: D6.1 (K), U6.14 (~RTS)
unnamed: D7.2 (A), R18.2
unnamed: J7.A5 (CC1), R7.2
unnamed: J7.B5 (CC2), R8.2
unnamed: R10.2, U7.2
unnamed: R11.2, U7.9
unnamed: R12.2, U7.5
unnamed: R13.2, U7.12
unnamed: R15.2, U2.1 (32KHZ)
unnamed: R14.1, U2.3 (~INT/SQW)
VCC: C11.1, C12.1, C15.1, C16.1, C18.1, C19.1, GPS1.8 (3.3V), J13.1 (Pin_1_1), MicroSD1.4 (VDD), R5.1, R9.2, R14.2, R15.1, R16.2, R17.2, R18.1, U1.2 (VDD), U2.2 (VCC), U3.5 (VDD), U4.2 (VO), U6.4 (V3), U6.16 (VCC), U7.14 (VCC)

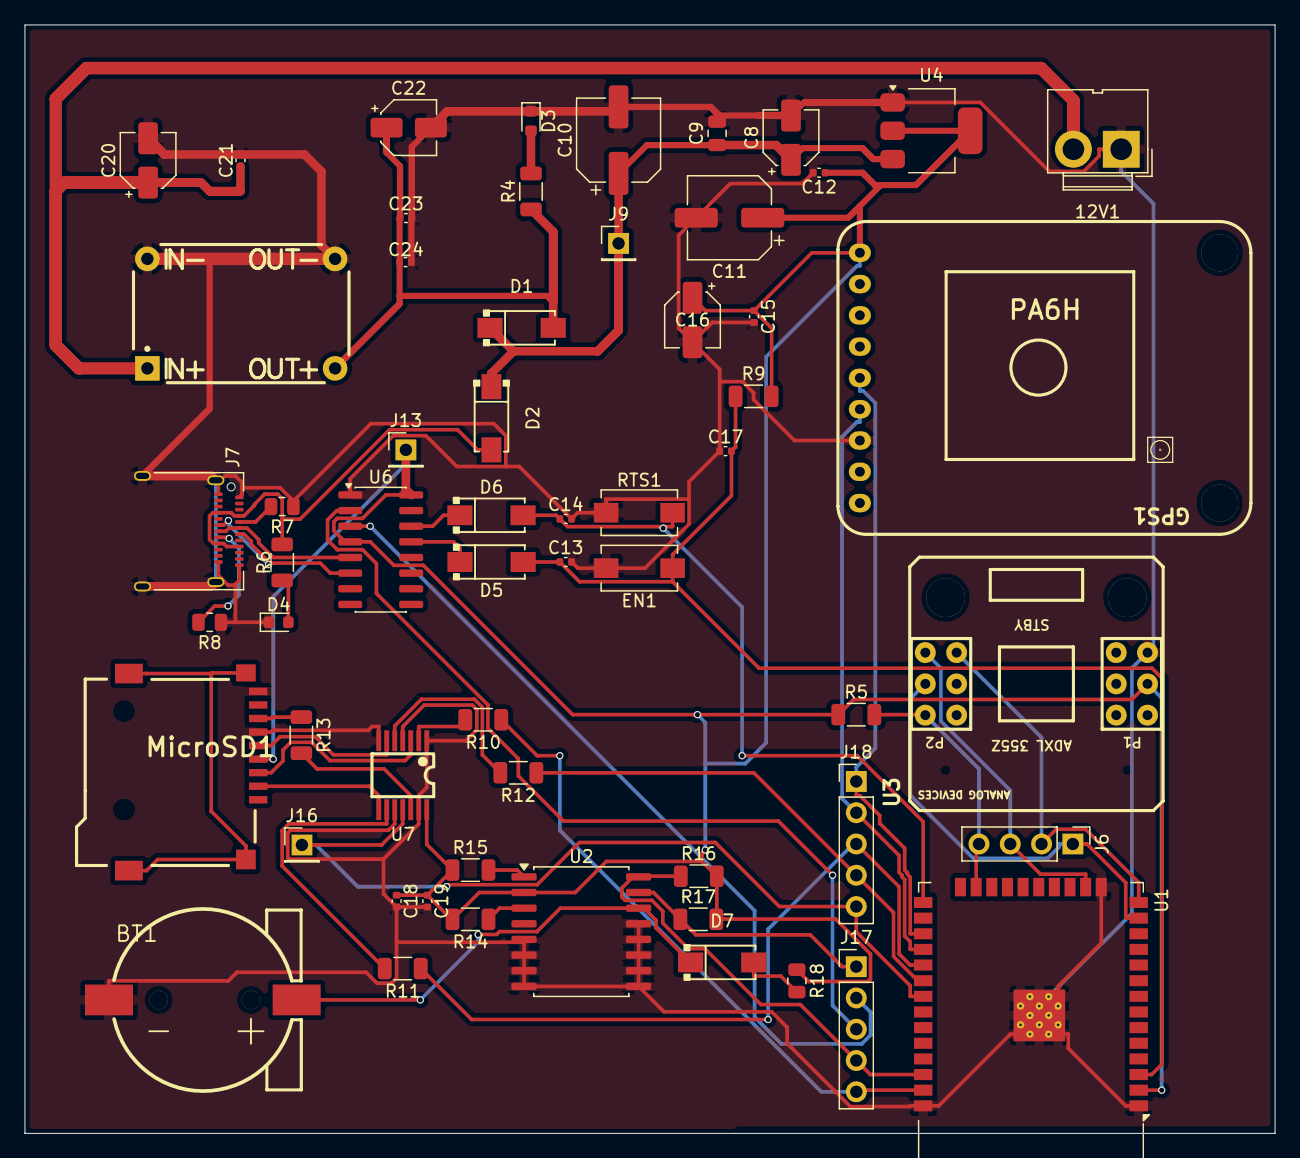
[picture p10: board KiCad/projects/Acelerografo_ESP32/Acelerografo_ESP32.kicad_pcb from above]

Board: 2 copper layers, 101.5 x 90.0 mm, 59 parts (0 on the bottom side), 42 nets.

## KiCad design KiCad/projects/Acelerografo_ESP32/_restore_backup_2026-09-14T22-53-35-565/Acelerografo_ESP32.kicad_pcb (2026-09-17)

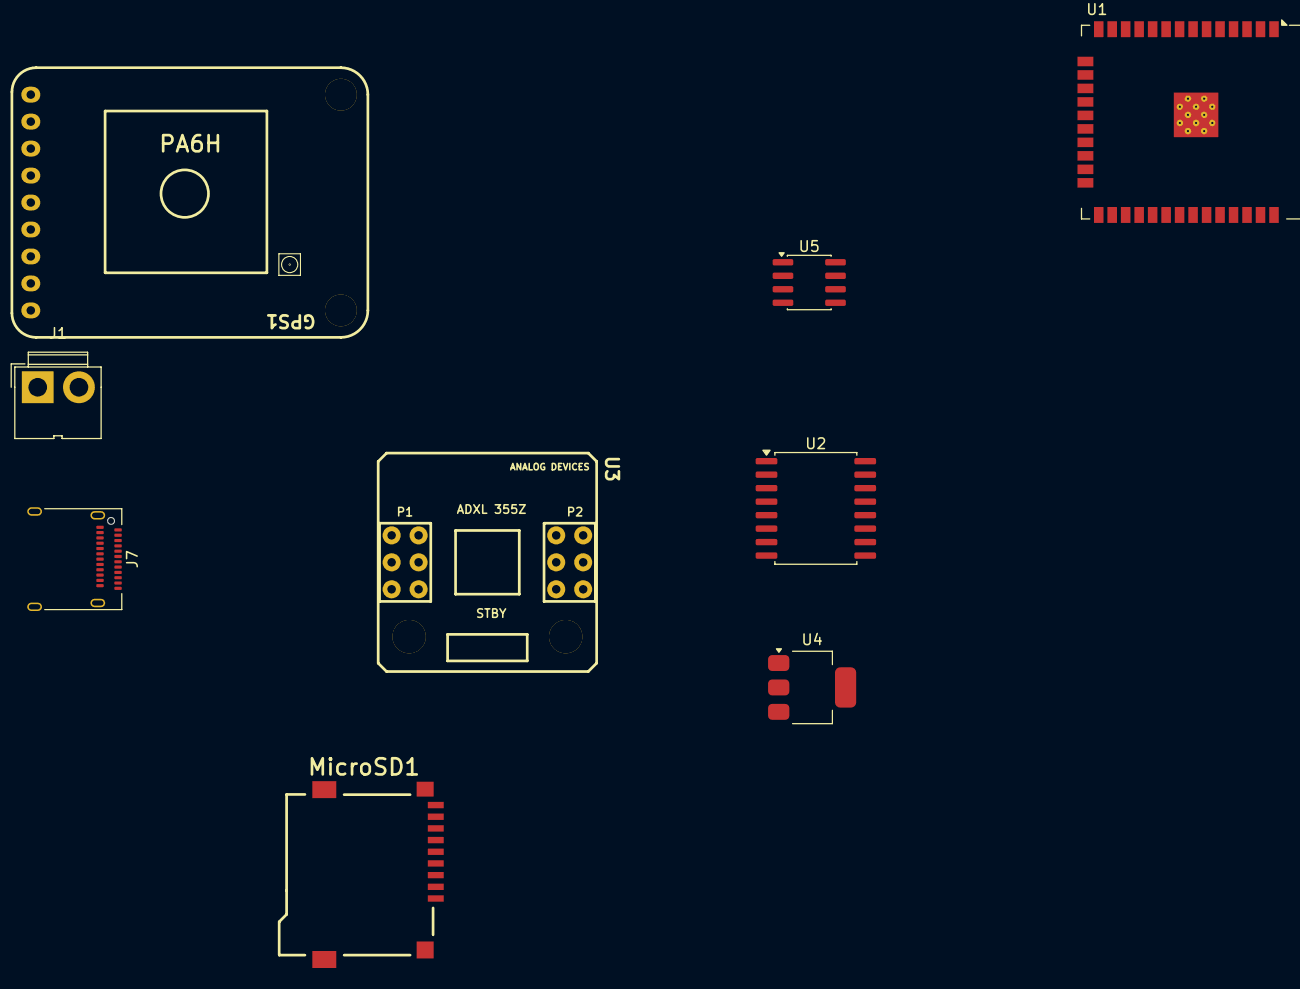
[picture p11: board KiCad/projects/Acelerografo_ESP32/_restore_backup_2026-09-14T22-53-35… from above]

Board: 2 copper layers, 9 parts (0 on the bottom side), 7 nets, no tracks yet.

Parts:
GPS1: GPS_BREAKOUT_V3
J1: Conn_01x02; JWT_A3963_1x02_P3.96mm_Vertical
J7: USB_C_Receptacle; USB_C_Receptacle_Amphenol_12401610E4-2A
MicroSD1: MicroSD_holder
U1: ESP32-WROOM-32
U2: DS3231M; SOIC-16W_7.5x10.3mm_P1.27mm
U3: ADXL355Z
U4: LD1117S33TR_SOT223; SOT-223-3_TabPin2
U5: MP2307; SOIC-8_3.9x4.9mm_P1.27mm

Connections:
/IN_MP2307: J1.2, U5.2 (IN)
/PWR_USB-C: J7.A4 (VBUS), J7.A9 (VBUS), J7.B4 (VBUS), J7.B9 (VBUS)
GND: GPS1.2 (GND), J1.1, U3.6 (GND), U4.1 (GND), U5.4 (GND)
unnamed: J7.A1 (GND), J7.A12 (GND), J7.B1 (GND), J7.B12 (GND)
unnamed: U1.1 (GND), U1.15 (GND), U1.38 (GND), U1.39 (GND)
unnamed: U2.5 (GND), U2.6 (GND), U2.7 (GND), U2.8 (GND), U2.9 (GND), U2.10 (GND), U2.11 (GND), U2.12 (GND), U2.13 (GND)
VCC: GPS1.8 (3.3V), U3.5 (VDD), U4.2 (VO)

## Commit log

2026-08-17 chore: inicializar repositorio con material de apoyo y archivos base para migracion a kicad
2026-09-17 Primera Revision
    [Acelerografo_ESP32.kicad_pcb, Acelerografo_ESP32.kicad_sch]
2026-10-08 Cambio Fuente de Alimentacion Modulo MP2307 y archivo JLPCB
    [Acelerografo_ESP32.csv, Acelerografo_ESP32.kicad_pcb, Acelerografo_ESP32.kicad_sch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]
2026-10-08 Cambio Fuente de Alimentacion Modulo MP2307 y archivo JLPCB 2
